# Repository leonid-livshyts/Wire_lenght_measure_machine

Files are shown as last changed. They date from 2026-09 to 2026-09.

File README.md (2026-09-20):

# Intro

It's machine which will count how much wire have gone though it and wind a new rope hank with an acurate length. It consists of roll which is connected to the encoder by gears and counts how much string have gone through it and a motor which pulls the string through the machine. It's controlled by RP2350b. The display and additional encoder will help to set the length of needed hank and to calibrate the mechanism. The mechanism is powered with 12V, 2A power supply. It has a small motor driver to controll speed and smothly controll the stop of the machine. 

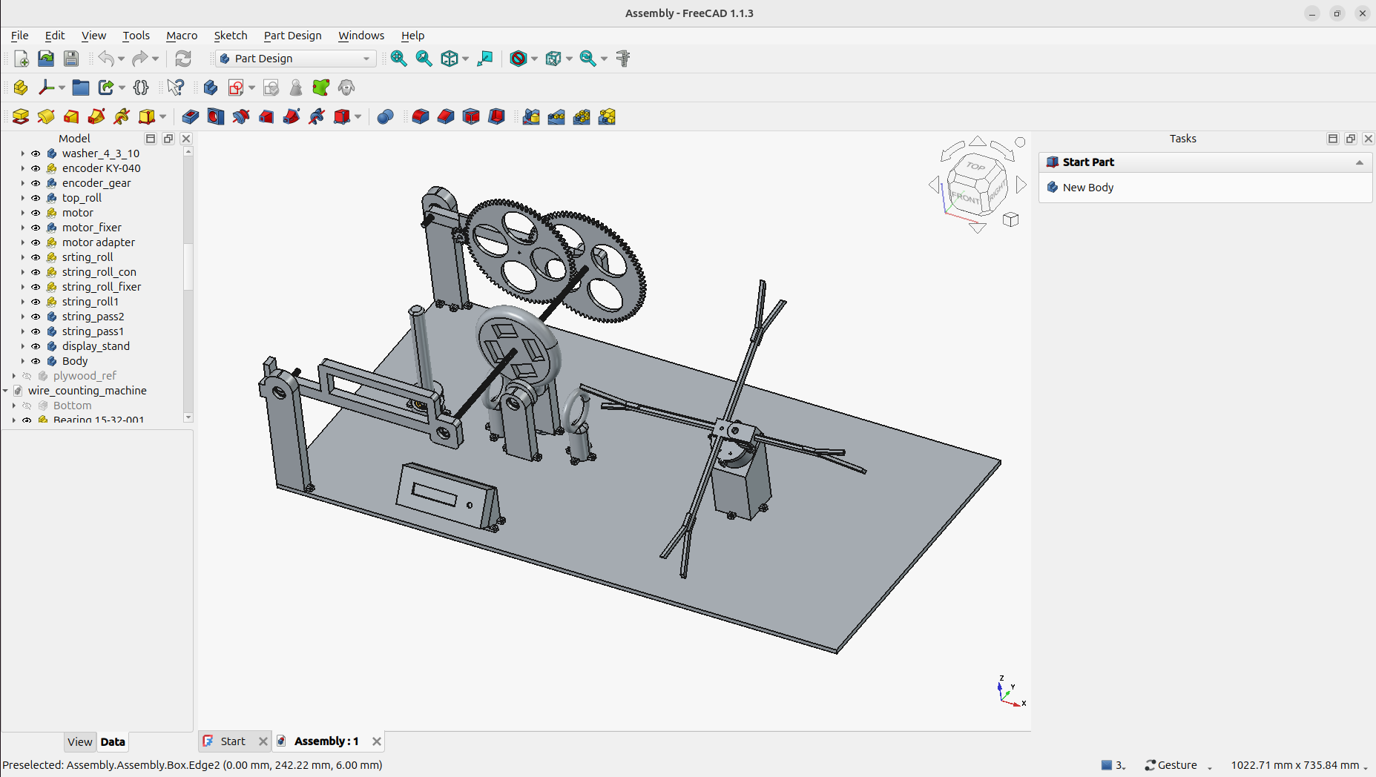
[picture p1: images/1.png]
Design without places for electronics


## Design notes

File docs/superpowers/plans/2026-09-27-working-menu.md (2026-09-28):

# Working Menu Implementation Plan

> **For agentic workers:** REQUIRED SUB-SKILL: Use superpowers:subagent-driven-development (recommended) or superpowers:executing-plans to implement this plan task-by-task. Steps use checkbox (`- [ ]`) syntax for tracking.

**Goal:** Replace the placeholder Working menu (`run 1` / `run 2`) with the real five-page flow: set the target length, set the max speed, thread the wire (counting on, motor off), pull (motor on, long-click pause/resume, stall stop, slow-down to a closed-loop creep speed and stop at target − 1 mm), and show the final length.

**Architecture:** Same split as the calibration menu.
- Hardware-free, host-tested pieces:
  - `ClickDetector` also reports **long clicks**.
  - `Menu` / `MenuManager` pass a user-knob long click to the shown tab.
  - `KnobAccel` gets an optional ×1000 step and a `clampAdd()` helper.
  - `run_logic.{h,cpp}` holds the pure maths of a run: when to slow down and stop, `SpeedMeter`, `CreepController` (holds the creep speed by measuring the wire), `StallDetector`.
- `Motor` gets `setSpeed(speed, ramp_ms)` (an exact power with its own ramp time, 0 = at once) and `isRamping()`, so the creep phase can steer the power and stop instantly.
- SDK-touching pages:
  - `number_edit_tab.{h,cpp}` is a generic "edit a number with the knob" page. It is used by the working menu's pages 1–2 and replaces `CalLengthTab`.
  - `working_menu.{h,cpp}` holds pages 3–5 and `WorkingMenu`.

**Tech Stack:** C++17, Raspberry Pi Pico SDK 2.3.1 (RP2350B, Ninja), host tests with the system `g++` and the existing `CHECK` macro.

## Global Constraints

- The pages, in order (from the user's spec):
  1. **Length:** the user sets the wanted wire length with the user knob. Uses the calibration menu's speed-dependent step.
  2. **Max speed:** in percent, default **100 %**, with the same knob system.
  3. **Thread:** counting is active and the display shows how much wire has gone through, but the **motor does not start**. The user puts the wire into the machine.
  4. **Pull:** the motor starts and the display shows the pulled length.
     - A **long click** pauses the motor, and another long click resumes it. The measuring encoder keeps counting while paused.
     - A **short click** goes to page 5. The page never advances by itself.
     - If the target is not reached yet and the motor runs while the measuring encoder sees **no movement for 10 s**, the motor stops.
  5. **Done:** stop the motor if it is not stopped already, show the final length, and stop counting.
- User decisions (asked 2026-09-27):
  - **Long click** = the user knob is released after being held **more than 2 s** (`ClickDetector::kShortClickMaxMs`). Nothing happens while it is held. A press of 2 s or less is a short click, as today.
  - **Target reached:** brake **early**, so the wire stops as close to the target as possible. The motor is not started at all if the target is already reached.
  - **Landing (user, 2026-09-28):** one fixed braking distance cannot be right, so the machine steers by the measured speed instead. Near the target, the motor slows down to a **creep speed in mm/s**. That speed is a constant, to be determined on the machine. During the creep the power is corrected from the measured wire speed. When the pulled length reaches **target − 1 mm**, the motor stops **at once**.
  - Target length and speed are **kept in RAM** between runs. At power-up they are reset to the defaults (1000 mm, 100 %). **Nothing is written to flash.**
  - The length is shown in **mm**. The knob step is **1 / 10 / 100 / 1000 mm** per detent, depending on turning speed.
- Page 1 range: **1 … 99 999 999 mm** (8 digits), default **1000**. Page 2 range: **1 … 100 %**, step ×1 / ×10 at most (×100 would just jump to a limit).
- Display texts (the font has no `M`/`X`):
  - Page 2 shows `SP` plus the number, right-aligned (`SP   100`).
  - A pulled length that needs more than 8 digits shows `--------`, as in calibration.
  - While paused or stalled, page 4 **blinks** (500 ms on / 500 ms off).
- The pulled length is `ticksToMm(measure.getCount(), settings.mm_per_tick)` (from `calibration.h`). The sign of the count is ignored.
- Stall detection runs **only while the motor is driving**: running, slowing down or creeping. It does not run while paused or stopped. One count step of jitter is not movement: movement is **≥ 4 ticks** (one detent).
- Landing model (every constant marked TUNE is a first guess, to be set on the machine):
  - **Slow-down point.** `Motor` ramps along a smoothstep over `Motor::kDefaultRampMs`, and a smoothstep's average is the mean of the start and end speeds. Ramping from speed `v` down to the creep speed therefore passes `(v + kCreepSpeedMmPerS) / 2 × ramp`. The slow-down starts when `pulled + that distance + kCreepMinMm ≥ target`.
    - `kCreepSpeedMmPerS = 20` (TUNE)
    - `kCreepMinMm = 20` (TUNE): the shortest creep, so the speed has time to settle.
  - **First creep power.** Wire speed is assumed proportional to power, so the first guess is `current power × creep / measured speed`. It is clamped to `[kCreepMinPower, current power]`.
  - **Creep control.** Every `SpeedMeter::kWindowMs` (100 ms), `power += kCreepGainPerMmS × (creep − measured)`, clamped to `[kCreepMinPower, max speed %]`.
    - `kCreepMinPower = 0.05` (TUNE)
    - `kCreepGainPerMmS = 0.002` (TUNE)
    - Power changes use a 100 ms ramp (`kCreepRampMs`).
    - The last creep power is remembered and used when a run resumes close to the target.
  - **Stop.** At `pulled ≥ target − kStopBeforeMm`, where `kStopBeforeMm = 1`, the power is set to 0 at once (`Motor::setSpeed(0, 0)`).
  - **Short target or resume.** If the target is no more than `kCreepMinMm` away when the motor starts or resumes, there is no fast phase: it creeps straight away.
- The hardware-free files (`click_detector.*`, `menu*.*`, `knob_accel.*`, `run_logic.*`) must not include Pico SDK headers.
- No heap: no `new`, `std::function`, `std::vector` or `std::string`.
- Code style: `snake_case_` members, `camelCase()` methods, `kConstant` constants, 4-space indent, `#pragma once`, and the comment density of the existing files.
- Every new firmware `.cpp` goes into `add_executable(Code ...)` in `Code/CMakeLists.txt`. Every new hardware-free `.cpp` also goes into `SOURCES` in `Code/tests/run_tests.sh`. Do not edit the `DO NOT EDIT` block.
- The working tree has unrelated changes (Case/, PCB/). **Commit only the paths listed in each task** (`git commit -- <paths>` after `git add <paths>`). Never use `git add -A` or `git commit -a`.

## File Structure

All paths are relative to the repository root.

| File | Responsibility |
|---|---|
| `Code/click_detector.{h,cpp}` (modify) | `ClickEvent { None, Short, Long }`; `update()` returns it |
| `Code/menu.{h,cpp}` (modify) | `MenuTab::onLongClick()`, `Menu::longClick()` |
| `Code/menu_manager.{h,cpp}` (modify) | `MenuInput::user_long_click`, forwarded to the open menu |
| `Code/knob_accel.{h,cpp}` (modify) | `max_factor` cap, ×1000 level, `clampAdd()` |
| `Code/run_logic.{h,cpp}` (create) | Target/speed limits, landing constants, `slowDownDistanceMm()`, `shouldSlowDown()`, `shouldStop()`, `estimateCreepPower()`, `SpeedMeter`, `CreepController`, `StallDetector` |
| `Code/motor.{h,cpp}` (modify) | `setSpeed(speed, ramp_ms)`, `isRamping()`; per-ramp duration |
| `Code/number_edit_tab.{h,cpp}` (create) | `NumberEditTab`: generic knob-edited number page with an optional 2-char label |
| `Code/calibration_menu.{h,cpp}` (modify) | `CalLengthTab` replaced by `NumberEditTab` |
| `Code/working_menu.{h,cpp}` (create) | `WorkingContext`, `RunThreadTab`, `RunPullTab`, `RunDoneTab`, `WorkingMenu` |
| `Code/Code.cpp` (modify) | Long clicks into `MenuInput`; real Working menu instead of the placeholders |
| `Code/CMakeLists.txt` (modify) | New sources |
| `Code/tests/*` (modify / create) | Tests per unit, registration |
| `Code/CLAUDE.md`, `Instructions/working.md` (modify / create) | Developer and user docs |

Commands used throughout (run from the repo root):
- Host tests: `Code/tests/run_tests.sh` → last line `All tests passed`
- Firmware build: `~/.pico-sdk/ninja/v1.13.2/ninja -C Code/build` → ends without `error:`, and `Code/build/Code.uf2` is updated

---

### Task 1: Long clicks in `ClickDetector`

**Files:**
- Modify: `Code/click_detector.h`, `Code/click_detector.cpp`
- Modify: `Code/tests/test_click_detector.cpp`
- Modify: `Code/Code.cpp` (keep the firmware compiling)

**Interfaces:**
- Consumes: nothing new.
- Produces: `enum class ClickEvent : uint8_t { None, Short, Long };` and `ClickEvent ClickDetector::update(bool pressed, uint32_t now_ms)`. On release, the result is `Short` if the press lasted ≤ `max_short_ms`, otherwise `Long`. It is `None` in every other pass.

- [ ] **Step 1: Rewrite the tests for the new return type**

Replace the whole content of `Code/tests/test_click_detector.cpp` with:

```cpp
#include "check.h"
#include "click_detector.h"

namespace {

void testNoPressNoClick() {
    ClickDetector d;
    CHECK(d.update(false, 0) == ClickEvent::None);
    CHECK(d.update(false, 100) == ClickEvent::None);
}

void testShortPressClicksOnceOnRelease() {
    ClickDetector d;
    CHECK(d.update(true, 1000) == ClickEvent::None);   // pressed: nothing yet
    CHECK(d.update(true, 1100) == ClickEvent::None);   // still held
    CHECK(d.update(false, 1150) == ClickEvent::Short); // released after 150 ms
    CHECK(d.update(false, 1200) == ClickEvent::None);  // reported only once
}

void testPressExactlyAtLimitIsShort() {
    ClickDetector d;
    d.update(true, 0);
    CHECK(d.update(false, ClickDetector::kShortClickMaxMs) == ClickEvent::Short);
}

void testLongPressReportsLongOnRelease() {
    ClickDetector d;
    d.update(true, 0);
    CHECK(d.update(true, 5000) == ClickEvent::None);  // nothing while held, however long
    CHECK(d.update(false, 5001) == ClickEvent::Long);
    CHECK(d.update(false, 5100) == ClickEvent::None); // reported only once
}

void testJustOverLimitIsLong() {
    ClickDetector d;
    d.update(true, 0);
    CHECK(d.update(false, ClickDetector::kShortClickMaxMs + 1) == ClickEvent::Long);
}

void testCustomLimit() {
    ClickDetector d(500);
    d.update(true, 0);
    CHECK(d.update(false, 600) == ClickEvent::Long);   // 600 ms > 500 ms
    d.update(true, 1000);
    CHECK(d.update(false, 1400) == ClickEvent::Short); // 400 ms
}

void testMillisecondCounterWraparound() {
    ClickDetector d;
    d.update(true, 0xFFFFFF00u);                      // 256 ms before the uint32_t wrap
    CHECK(d.update(false, 100) == ClickEvent::Short); // 356 ms later
    d.update(true, 0xFFFFFF00u);
    CHECK(d.update(false, 3000) == ClickEvent::Long); // 3256 ms later
}

}  // namespace

void runClickDetectorTests() {
    testNoPressNoClick();
    testShortPressClicksOnceOnRelease();
    testPressExactlyAtLimitIsShort();
    testLongPressReportsLongOnRelease();
    testJustOverLimitIsLong();
    testCustomLimit();
    testMillisecondCounterWraparound();
}
```

- [ ] **Step 2: Run the tests and check that they fail**

Run: `Code/tests/run_tests.sh`
Expected: compile error, `'ClickEvent' has not been declared`.

- [ ] **Step 3: Implement `ClickEvent`**

Replace the whole content of `Code/click_detector.h` with:

```cpp
#pragma once

#include <stdint.h>

// What one press of a button turned out to be, reported on release.
enum class ClickEvent : uint8_t {
    None,   // no release in this pass
    Short,  // held for at most max_short_ms: flips menu pages
    Long,   // held longer: e.g. pause/resume while pulling wire
};

// Turns a debounced button level into short and long clicks.
//
// Both are reported once, on release, so nothing happens while the button
// is held. Pure logic (no SDK calls), so it is unit-tested on the host; the
// caller passes the time in.
class ClickDetector {
public:
    static constexpr uint32_t kShortClickMaxMs = 2000;

    explicit ClickDetector(uint32_t max_short_ms = kShortClickMaxMs);

    // Call regularly with the current button state and time. Returns Short
    // or Long exactly once per press (on release), None otherwise.
    // now_ms may wrap around.
    ClickEvent update(bool pressed, uint32_t now_ms);

private:
    uint32_t max_short_ms_;
    bool was_pressed_ = false;
    uint32_t press_start_ms_ = 0;
};
```

Replace the whole content of `Code/click_detector.cpp` with:

```cpp
#include "click_detector.h"

ClickDetector::ClickDetector(uint32_t max_short_ms) : max_short_ms_(max_short_ms) {}

ClickEvent ClickDetector::update(bool pressed, uint32_t now_ms) {
    if (pressed && !was_pressed_) press_start_ms_ = now_ms;
    bool released = !pressed && was_pressed_;
    was_pressed_ = pressed;
    if (!released) return ClickEvent::None;

    // Unsigned subtraction keeps the duration right across a counter wrap
    return (uint32_t)(now_ms - press_start_ms_) <= max_short_ms_ ? ClickEvent::Short
                                                                 : ClickEvent::Long;
}
```

In `Code/Code.cpp`, in the main loop, replace:

```cpp
        input.user_click = userClicks.update(userEncoder.isPressed(), now);
        input.measure_click = measureClicks.update(measureEncoder.isPressed(), now);
```

with:

```cpp
        input.user_click = userClicks.update(userEncoder.isPressed(), now) == ClickEvent::Short;
        input.measure_click = measureClicks.update(measureEncoder.isPressed(), now) == ClickEvent::Short;
```

- [ ] **Step 4: Run the tests and the firmware build**

Run: `Code/tests/run_tests.sh` → Expected: `All tests passed`
Run: `~/.pico-sdk/ninja/v1.13.2/ninja -C Code/build` → Expected: builds without errors.

- [ ] **Step 5: Commit**

```bash
git add Code/click_detector.h Code/click_detector.cpp Code/tests/test_click_detector.cpp Code/Code.cpp
git commit -m "feat(firmware): report long clicks from ClickDetector" -- Code/click_detector.h Code/click_detector.cpp Code/tests/test_click_detector.cpp Code/Code.cpp
```

---

### Task 2: Long click through `Menu` and `MenuManager`

**Files:**
- Modify: `Code/menu.h`, `Code/menu.cpp`, `Code/menu_manager.h`, `Code/menu_manager.cpp`
- Modify: `Code/tests/fake_tab.h`, `Code/tests/test_menu.cpp`, `Code/tests/test_menu_manager.cpp`
- Modify: `Code/Code.cpp`

**Interfaces:**
- Consumes: `ClickEvent` (Task 1).
- Produces:
  - `virtual TabAction MenuTab::onLongClick()`, default `TabAction::Stay`.
  - `void Menu::longClick()`, ignored while the menu is closed.
  - `bool MenuInput::user_long_click`. It is forwarded to the open menu. It **never opens a menu** while idle.

- [ ] **Step 1: Extend `FakeTab`**

In `Code/tests/fake_tab.h`, add the members below after `bool skipped = false;  // isSkipped() result`:

```cpp
    int long_clicks = 0;
    TabAction long_click_action = TabAction::Stay;
```

and this override after the `onClick()` override:

```cpp
    TabAction onLongClick() override { long_clicks++; return long_click_action; }
```

- [ ] **Step 2: Write the failing menu tests**

In `Code/tests/test_menu.cpp`, add these inside the anonymous namespace, before its closing `}  // namespace`:

```cpp
void testLongClickGoesToShownTab() {
    FakeTab a, b;
    Menu m;
    m.addTab(a);
    m.addTab(b);
    m.open();
    m.longClick();
    CHECK(a.long_clicks == 1);
    CHECK(a.clicks == 0);
    CHECK(m.currentTab() == 0);  // default: Stay

    a.long_click_action = TabAction::Next;
    m.longClick();
    CHECK(m.currentTab() == 1);
    CHECK(b.long_clicks == 0);
}

void testLongClickWhileClosedIsIgnored() {
    FakeTab a;
    Menu m;
    m.addTab(a);
    m.longClick();
    CHECK(a.long_clicks == 0);
    CHECK(!m.isOpen());
}
```

and add at the end of `runMenuTests()`:

```cpp
    testLongClickGoesToShownTab();
    testLongClickWhileClosedIsIgnored();
```

In `Code/tests/test_menu_manager.cpp`, add this helper after `MenuInput userTurn(...)`:

```cpp
MenuInput userLongClick() { MenuInput in; in.user_long_click = true; return in; }
```

add these tests inside the anonymous namespace, before its closing `}  // namespace`:

```cpp
void testLongClickDoesNotOpenMenu() {
    Fixture f;
    f.manager.process(userLongClick(), 0);
    CHECK(f.manager.activeMenu() == nullptr);
    CHECK(f.work1.enters == 0);
    CHECK(f.cal1.enters == 0);
}

void testLongClickReachesOpenTab() {
    Fixture f;
    f.manager.process(userClick(), 0);
    f.manager.process(userLongClick(), 5);
    CHECK(f.work1.long_clicks == 1);
    CHECK(f.work1.clicks == 0);
    CHECK(f.manager.activeMenu() == &f.working);
}
```

and add at the end of `runMenuManagerTests()`:

```cpp
    testLongClickDoesNotOpenMenu();
    testLongClickReachesOpenTab();
```

- [ ] **Step 3: Run the tests and check that they fail**

Run: `Code/tests/run_tests.sh`
Expected: compile errors, e.g. `'class Menu' has no member named 'longClick'`, and `'onLongClick' marked 'override', but does not override`.

- [ ] **Step 4: Implement**

In `Code/menu.h`, in `MenuTab`, after the `onClick()` declaration add:

```cpp
    // Long click on the user encoder (held > 2 s, reported on release).
    // Default: ignored.
    virtual TabAction onLongClick() { return TabAction::Stay; }
```

In `Code/menu.h`, in `Menu`, change the input declarations to:

```cpp
    // Input for the shown tab; ignored while closed.
    void turn(int32_t detents);
    void click();
    void longClick();
    void update(uint32_t now_ms);
```

In `Code/menu.cpp`, after `Menu::click()` add:

```cpp
void Menu::longClick() {
    if (isOpen()) apply(tabs_[current_]->onLongClick());
}
```

In `Code/menu_manager.h`, change `MenuInput` to:

```cpp
struct MenuInput {
    int32_t user_turn = 0;         // user knob detents since the last pass
    bool user_click = false;       // short click on the user knob
    bool user_long_click = false;  // long click on the user knob; never opens a menu
    bool measure_click = false;    // short click on the measuring-roll encoder
};
```

In `Code/menu_manager.cpp`, in `process()`, change the open-menu branch to:

```cpp
        active_->turn(input.user_turn);
        if (input.user_click) active_->click();
        if (input.user_long_click) active_->longClick();
```

In `Code/Code.cpp`, replace the line

```cpp
        input.user_click = userClicks.update(userEncoder.isPressed(), now) == ClickEvent::Short;
```

with:

```cpp
        ClickEvent user_click = userClicks.update(userEncoder.isPressed(), now);
        input.user_click = user_click == ClickEvent::Short;
        input.user_long_click = user_click == ClickEvent::Long;
```

- [ ] **Step 5: Run the tests and the firmware build**

Run: `Code/tests/run_tests.sh` → Expected: `All tests passed`
Run: `~/.pico-sdk/ninja/v1.13.2/ninja -C Code/build` → Expected: builds without errors.

- [ ] **Step 6: Commit**

```bash
git add Code/menu.h Code/menu.cpp Code/menu_manager.h Code/menu_manager.cpp Code/tests/fake_tab.h Code/tests/test_menu.cpp Code/tests/test_menu_manager.cpp Code/Code.cpp
git commit -m "feat(firmware): pass user-knob long clicks to the shown tab" -- Code/menu.h Code/menu.cpp Code/menu_manager.h Code/menu_manager.cpp Code/tests/fake_tab.h Code/tests/test_menu.cpp Code/tests/test_menu_manager.cpp Code/Code.cpp
```

---

### Task 3: `KnobAccel` ×1000 level and `clampAdd()`

**Files:**
- Modify: `Code/knob_accel.h`, `Code/knob_accel.cpp`, `Code/tests/test_knob_accel.cpp`

**Interfaces:**
- Consumes: nothing new.
- Produces:
  - `explicit KnobAccel(int32_t max_factor = 100)`. The step is ×1000 for gaps ≤ `kFastestGapMs` (20 ms), then capped at `max_factor`. The default of 100 keeps the calibration page exactly as it is today.
  - `int32_t clampAdd(int32_t value, int32_t delta, int32_t min_value, int32_t max_value)`: overflow-safe add, then clamp.

- [ ] **Step 1: Write the failing tests**

In `Code/tests/test_knob_accel.cpp`, add inside the anonymous namespace, before `}  // namespace`:

```cpp
void testFastestTurnsNeedCap1000() {
    KnobAccel wide(1000);
    wide.scale(1, 1000);
    CHECK(wide.scale(1, 1000 + KnobAccel::kFastestGapMs) == 1000);
    CHECK(wide.scale(-1, 1020 + KnobAccel::kFastGapMs) == -100);  // 40 ms: x100

    KnobAccel normal;  // default cap 100: calibration unchanged
    normal.scale(1, 1000);
    CHECK(normal.scale(1, 1000 + KnobAccel::kFastestGapMs) == 100);
}

void testSmallCap() {
    KnobAccel narrow(10);
    narrow.scale(1, 1000);
    CHECK(narrow.scale(1, 1005) == 10);  // fastest turn still only x10
    CHECK(narrow.scale(1, 5000) == 1);
}

void testClampAdd() {
    CHECK(clampAdd(50, 10, 1, 100) == 60);
    CHECK(clampAdd(95, 10, 1, 100) == 100);
    CHECK(clampAdd(5, -10, 1, 100) == 1);
    CHECK(clampAdd(INT32_MAX - 1, INT32_MAX, 1, INT32_MAX) == INT32_MAX);  // no overflow
    CHECK(clampAdd(1, INT32_MIN, 1, 100) == 1);
}
```

Add `#include <cstdint>` at the top of the file, and add at the end of `runKnobAccelTests()`:

```cpp
    testFastestTurnsNeedCap1000();
    testSmallCap();
    testClampAdd();
```

- [ ] **Step 2: Run the tests and check that they fail**

Run: `Code/tests/run_tests.sh`
Expected: compile errors: `'kFastestGapMs' is not a member of 'KnobAccel'`, and `'clampAdd' was not declared`.

- [ ] **Step 3: Implement**

Replace the whole content of `Code/knob_accel.h` with:

```cpp
#pragma once

#include <stdint.h>

// Speed-dependent step for editing a number with the user knob: slow turns
// change it by 1 per detent, faster turns by 10, 100 or 1000, so both fine
// adjustment and big jumps are quick. Pure logic; the caller passes the time.
class KnobAccel {
public:
    static constexpr uint32_t kFastestGapMs = 20;  // turns this close: x1000
    static constexpr uint32_t kFastGapMs = 40;     // turns this close: x100
    static constexpr uint32_t kMediumGapMs = 100;  // turns this close: x10

    // max_factor caps the step: 100 by default, 1000 for long lengths,
    // 10 for small ranges where x100 would only jump to a limit.
    explicit KnobAccel(int32_t max_factor = 100) : max_factor_(max_factor) {}

    // Returns detents scaled by the factor for the gap since the previous
    // turn. detents == 0 returns 0 and is not counted as a turn. now_ms may wrap around.
    int32_t scale(int32_t detents, uint32_t now_ms);

    // Forgets the previous turn, so the next one is x1.
    void reset();

private:
    int32_t max_factor_;
    bool has_last_ = false;
    uint32_t last_ms_ = 0;
};

// value + delta, clamped to [min_value, max_value]. Safe for any int32 inputs.
int32_t clampAdd(int32_t value, int32_t delta, int32_t min_value, int32_t max_value);
```

Replace the whole content of `Code/knob_accel.cpp` with:

```cpp
#include "knob_accel.h"

int32_t KnobAccel::scale(int32_t detents, uint32_t now_ms) {
    if (detents == 0) return 0;
    int32_t factor = 1;
    if (has_last_) {
        uint32_t gap = now_ms - last_ms_;  // unsigned: correct across the wrap
        if (gap <= kFastestGapMs) {
            factor = 1000;
        } else if (gap <= kFastGapMs) {
            factor = 100;
        } else if (gap <= kMediumGapMs) {
            factor = 10;
        }
    }
    if (factor > max_factor_) factor = max_factor_;
    has_last_ = true;
    last_ms_ = now_ms;
    return detents * factor;
}

void KnobAccel::reset() {
    has_last_ = false;
}

int32_t clampAdd(int32_t value, int32_t delta, int32_t min_value, int32_t max_value) {
    int64_t sum = (int64_t)value + delta;  // int64: no overflow
    if (sum < min_value) return min_value;
    if (sum > max_value) return max_value;
    return (int32_t)sum;
}
```

- [ ] **Step 4: Run the tests**

Run: `Code/tests/run_tests.sh` → Expected: `All tests passed`. This includes the old KnobAccel tests, which are unchanged.

- [ ] **Step 5: Commit**

```bash
git add Code/knob_accel.h Code/knob_accel.cpp Code/tests/test_knob_accel.cpp
git commit -m "feat(firmware): optional x1000 knob step and clampAdd helper" -- Code/knob_accel.h Code/knob_accel.cpp Code/tests/test_knob_accel.cpp
```

---

### Task 4: Run maths (`run_logic.{h,cpp}`)

**Files:**
- Create: `Code/run_logic.h`, `Code/run_logic.cpp`, `Code/tests/test_run_logic.cpp`
- Modify: `Code/tests/run_tests.sh`, `Code/tests/test_main.cpp`

**Interfaces:**
- Consumes: nothing.
- Produces (all in `run_logic.h`):
  - `kMinTargetMm = 1`, `kMaxTargetMm = 99999999`, `kDefaultTargetMm = 1000`
  - `kMinSpeedPercent = 1`, `kMaxSpeedPercent = 100`, `kDefaultSpeedPercent = 100`
  - `kCreepSpeedMmPerS = 20.0`, `kCreepMinMm = 20`, `kStopBeforeMm = 1`, `kCreepMinPower = 0.05f`, `kCreepGainPerMmS = 0.002f`
  - `double slowDownDistanceMm(double speed_mm_per_s, uint32_t ramp_ms)`
  - `bool shouldSlowDown(int64_t pulled_mm, int32_t target_mm, double speed_mm_per_s, uint32_t ramp_ms)`
  - `bool shouldStop(int64_t pulled_mm, int32_t target_mm)`
  - `float estimateCreepPower(float power, double speed_mm_per_s)`
  - `class SpeedMeter { void reset(int64_t mm, uint32_t now_ms); double update(int64_t mm, uint32_t now_ms); }`, with `kWindowMs = 100`
  - `class CreepController { void start(float power, float max_power, uint32_t now_ms); float update(double speed_mm_per_s, uint32_t now_ms); float power() const; }`
  - `class StallDetector { void reset(int32_t count, uint32_t now_ms); bool update(int32_t count, uint32_t now_ms); }`, with `kTimeoutMs = 10000` and `kMinMoveTicks = 4`

The tests compute their expected values from the TUNE constants, so they keep passing after the constants are tuned.

- [ ] **Step 1: Write the failing tests**

Create `Code/tests/test_run_logic.cpp`:

```cpp
#include <cmath>

#include "check.h"
#include "run_logic.h"

namespace {

bool near(double a, double b) { return std::fabs(a - b) < 1e-6; }

void testSlowDownDistance() {
    // Smoothstep ramp from 120 mm/s to the creep speed over 2.5 s
    CHECK(near(slowDownDistanceMm(120.0, 2500), (120.0 + kCreepSpeedMmPerS) / 2.0 * 2.5));
    CHECK(near(slowDownDistanceMm(kCreepSpeedMmPerS, 2500), 0.0));  // already at creep speed
    CHECK(near(slowDownDistanceMm(0.0, 2500), 0.0));
}

void testShouldSlowDown() {
    double lead = slowDownDistanceMm(120.0, 2500) + kCreepMinMm;
    int64_t at = 1000 - (int64_t)std::floor(lead);  // first whole mm where the lead reaches 1000
    CHECK(shouldSlowDown(at, 1000, 120.0, 2500));
    CHECK(!shouldSlowDown(at - 1, 1000, 120.0, 2500));
    // Standing still: only the creep distance is needed
    CHECK(shouldSlowDown(1000 - kCreepMinMm, 1000, 0.0, 2500));
    CHECK(!shouldSlowDown(1000 - kCreepMinMm - 1, 1000, 0.0, 2500));
}

void testShouldStop() {
    CHECK(shouldStop(1000 - kStopBeforeMm, 1000));
    CHECK(!shouldStop(1000 - kStopBeforeMm - 1, 1000));
    CHECK(shouldStop(1005, 1000));  // overshot
}

void testEstimateCreepPower() {
    CHECK(near(estimateCreepPower(1.0f, kCreepSpeedMmPerS * 5.0), 0.2));  // speed ~ power
    CHECK(near(estimateCreepPower(0.5f, kCreepSpeedMmPerS / 2.0), 0.5));  // never above the current power
    CHECK(near(estimateCreepPower(0.3f, 0.0), 0.3));                      // no speed yet: keep the power
    CHECK(near(estimateCreepPower(1.0f, kCreepSpeedMmPerS * 1000.0), kCreepMinPower));
    CHECK(near(estimateCreepPower(0.02f, 0.0), kCreepMinPower));
}

void testCreepControllerAdjustsEveryWindow() {
    CreepController c;
    c.start(0.2f, 1.0f, 0);
    CHECK(near(c.update(kCreepSpeedMmPerS - 10.0, SpeedMeter::kWindowMs - 1), 0.2));  // not yet
    double faster = 0.2 + 10.0 * kCreepGainPerMmS;                                     // too slow: more power
    CHECK(near(c.update(kCreepSpeedMmPerS - 10.0, SpeedMeter::kWindowMs), faster));
    CHECK(near(c.update(kCreepSpeedMmPerS + 10.0, 2 * SpeedMeter::kWindowMs), 0.2)); // too fast: less
    CHECK(near(c.power(), 0.2));
}

void testCreepControllerClamps() {
    CreepController c;
    c.start(0.0f, 1.0f, 0);
    CHECK(near(c.power(), kCreepMinPower));
    CHECK(near(c.update(kCreepSpeedMmPerS + 1000.0, SpeedMeter::kWindowMs), kCreepMinPower));
    c.start(0.9f, 0.5f, 0);  // user max speed 50 %
    CHECK(near(c.power(), 0.5));
    CHECK(near(c.update(0.0, SpeedMeter::kWindowMs), 0.5));
}

void testSpeedMeterNeedsFullWindow() {
    SpeedMeter m;
    m.reset(0, 1000);
    CHECK(near(m.update(5, 1050), 0.0));     // window not full yet
    CHECK(near(m.update(10, 1100), 100.0));  // 10 mm in 100 ms
    CHECK(near(m.update(12, 1150), 100.0));  // keeps the last value mid-window
    CHECK(near(m.update(30, 1200), 200.0));  // 20 mm in the next 100 ms
}

void testSpeedMeterResetClearsSpeed() {
    SpeedMeter m;
    m.reset(0, 0);
    m.update(50, 100);
    m.reset(50, 200);
    CHECK(near(m.update(50, 250), 0.0));
}

void testSpeedMeterWraparound() {
    SpeedMeter m;
    m.reset(0, 0xFFFFFFC0u);                        // 64 ms before the wrap
    CHECK(near(m.update(10, 0x00000024u), 100.0));  // 100 ms later
}

void testStallAfterTimeout() {
    StallDetector s;
    s.reset(0, 0);
    CHECK(!s.update(0, StallDetector::kTimeoutMs - 1));
    CHECK(s.update(0, StallDetector::kTimeoutMs));
}

void testJitterIsNotMovement() {
    StallDetector s;
    s.reset(100, 0);
    CHECK(!s.update(103, 5000));                     // 3 ticks: jitter
    CHECK(s.update(97, StallDetector::kTimeoutMs));  // still no real movement
}

void testMovementRestartsTimeout() {
    StallDetector s;
    s.reset(0, 0);
    CHECK(!s.update(4, 5000));  // one detent: moving
    CHECK(!s.update(4, 14999));
    CHECK(s.update(4, 15000));
    StallDetector back;
    back.reset(0, 0);
    CHECK(!back.update(-4, 5000));  // either direction counts
    CHECK(!back.update(-4, 14999));
}

void testStallWraparound() {
    StallDetector s;
    s.reset(0, 0xFFFFF000u);
    CHECK(!s.update(0, 0x00001000u));  // 8192 ms across the wrap
}

}  // namespace

void runRunLogicTests() {
    testSlowDownDistance();
    testShouldSlowDown();
    testShouldStop();
    testEstimateCreepPower();
    testCreepControllerAdjustsEveryWindow();
    testCreepControllerClamps();
    testSpeedMeterNeedsFullWindow();
    testSpeedMeterResetClearsSpeed();
    testSpeedMeterWraparound();
    testStallAfterTimeout();
    testJitterIsNotMovement();
    testMovementRestartsTimeout();
    testStallWraparound();
}
```

In `Code/tests/test_main.cpp`, add `void runRunLogicTests();` after `void runCalibrationTests();`, and `runRunLogicTests();` after `runCalibrationTests();`.

In `Code/tests/run_tests.sh`, change the `SOURCES` line to:

```sh
SOURCES="../click_detector.cpp ../menu.cpp ../menu_manager.cpp ../knob_accel.cpp ../settings.cpp ../calibration.cpp ../run_logic.cpp"
```

- [ ] **Step 2: Run the tests and check that they fail**

Run: `Code/tests/run_tests.sh`
Expected: `fatal error: run_logic.h: No such file or directory`.

- [ ] **Step 3: Implement**

Create `Code/run_logic.h`:

```cpp
#pragma once

#include <stdint.h>

// Pure maths of the working menu (host-tested).

constexpr int32_t kMinTargetMm = 1;
constexpr int32_t kMaxTargetMm = 99999999;  // 8 display digits
constexpr int32_t kDefaultTargetMm = 1000;

constexpr int32_t kMinSpeedPercent = 1;
constexpr int32_t kMaxSpeedPercent = 100;
constexpr int32_t kDefaultSpeedPercent = 100;

// --- Landing on the target ---
// No single braking distance fits every speed and wire, so near the target
// the motor slows down to a creep speed, the power is corrected from the
// measured wire speed, and the motor stops at once kStopBeforeMm before the
// target; the wire coasts the rest. TUNE = first guess, set on the machine.
constexpr double kCreepSpeedMmPerS = 20.0;  // TUNE
constexpr int32_t kCreepMinMm = 20;         // shortest creep, so the speed settles; TUNE
constexpr int32_t kStopBeforeMm = 1;
constexpr float kCreepMinPower = 0.05f;     // lowest motor power while creeping; TUNE
constexpr float kCreepGainPerMmS = 0.002f;  // power change per mm/s of error, per adjustment; TUNE

// Wire that passes while the motor ramps from speed_mm_per_s down to the
// creep speed over ramp_ms. The ramp is a smoothstep, whose average speed is
// the mean of both ends. 0 if already at or below the creep speed.
double slowDownDistanceMm(double speed_mm_per_s, uint32_t ramp_ms);

// True once the motor must start slowing down to still creep kCreepMinMm
// before the target.
bool shouldSlowDown(int64_t pulled_mm, int32_t target_mm, double speed_mm_per_s, uint32_t ramp_ms);

// True once pulled_mm >= target_mm - kStopBeforeMm: stop the motor now.
bool shouldStop(int64_t pulled_mm, int32_t target_mm);

// First guess for the creep power, taking wire speed as proportional to
// power: power * creep / speed, at most `power`, at least kCreepMinPower.
// `power` itself (at least kCreepMinPower) while no speed is measured.
float estimateCreepPower(float power, double speed_mm_per_s);

// Wire speed from the pulled length, measured over windows of kWindowMs.
class SpeedMeter {
public:
    static constexpr uint32_t kWindowMs = 100;

    // Starts measuring from `mm`; the speed is 0 until a full window has passed.
    void reset(int64_t mm, uint32_t now_ms);

    // Call every pass. Returns the speed of the last full window in mm/s.
    // now_ms may wrap around.
    double update(int64_t mm, uint32_t now_ms);

private:
    int64_t window_mm_ = 0;
    uint32_t window_start_ms_ = 0;
    double speed_mm_per_s_ = 0.0;
};

// Holds the creep speed: every SpeedMeter::kWindowMs it moves the motor
// power by kCreepGainPerMmS per mm/s of error (a simple integral controller).
class CreepController {
public:
    // Starts from `power`, clamped to [kCreepMinPower, max_power]
    // (max_power = the user's max speed). The first adjustment comes one
    // window later.
    void start(float power, float max_power, uint32_t now_ms);

    // Call every pass with the measured wire speed. Returns the power to
    // drive. now_ms may wrap around.
    float update(double speed_mm_per_s, uint32_t now_ms);

    // Current power. Kept between runs as the best guess for the next creep.
    float power() const { return power_; }

private:
    float power_ = 0.2f;  // TUNE: guess before any creep has run
    float max_power_ = 1.0f;
    uint32_t last_adjust_ms_ = 0;
};

// Detects "motor driving but the wire does not move" from the raw count.
class StallDetector {
public:
    static constexpr uint32_t kTimeoutMs = 10000;
    static constexpr int32_t kMinMoveTicks = 4;  // one detent; less is encoder jitter

    void reset(int32_t count, uint32_t now_ms);

    // True once the count has not moved by kMinMoveTicks for kTimeoutMs.
    // now_ms may wrap around.
    bool update(int32_t count, uint32_t now_ms);

private:
    int32_t last_count_ = 0;
    uint32_t last_move_ms_ = 0;
};
```

Create `Code/run_logic.cpp`:

```cpp
#include "run_logic.h"

namespace {

// Clamped to [kCreepMinPower, max_power]; the minimum wins if they cross.
float clampPower(float power, float max_power) {
    if (power > max_power) power = max_power;
    if (power < kCreepMinPower) power = kCreepMinPower;
    return power;
}

}  // namespace

double slowDownDistanceMm(double speed_mm_per_s, uint32_t ramp_ms) {
    if (speed_mm_per_s <= kCreepSpeedMmPerS) return 0.0;
    return (speed_mm_per_s + kCreepSpeedMmPerS) / 2.0 * (ramp_ms / 1000.0);
}

bool shouldSlowDown(int64_t pulled_mm, int32_t target_mm, double speed_mm_per_s, uint32_t ramp_ms) {
    double lead = slowDownDistanceMm(speed_mm_per_s, ramp_ms) + kCreepMinMm;
    return (double)pulled_mm + lead >= (double)target_mm;
}

bool shouldStop(int64_t pulled_mm, int32_t target_mm) {
    return pulled_mm >= (int64_t)target_mm - kStopBeforeMm;
}

float estimateCreepPower(float power, double speed_mm_per_s) {
    float guess = speed_mm_per_s > 0.0 ? (float)(power * kCreepSpeedMmPerS / speed_mm_per_s) : power;
    return clampPower(guess, power);
}

void SpeedMeter::reset(int64_t mm, uint32_t now_ms) {
    window_mm_ = mm;
    window_start_ms_ = now_ms;
    speed_mm_per_s_ = 0.0;
}

double SpeedMeter::update(int64_t mm, uint32_t now_ms) {
    uint32_t elapsed = now_ms - window_start_ms_;  // unsigned: correct across the wrap
    if (elapsed >= kWindowMs) {
        speed_mm_per_s_ = (double)(mm - window_mm_) * 1000.0 / (double)elapsed;
        window_mm_ = mm;
        window_start_ms_ = now_ms;
    }
    return speed_mm_per_s_;
}

void CreepController::start(float power, float max_power, uint32_t now_ms) {
    max_power_ = max_power;
    power_ = clampPower(power, max_power);
    last_adjust_ms_ = now_ms;
}

float CreepController::update(double speed_mm_per_s, uint32_t now_ms) {
    if ((uint32_t)(now_ms - last_adjust_ms_) >= SpeedMeter::kWindowMs) {
        float error = (float)(kCreepSpeedMmPerS - speed_mm_per_s);  // > 0: too slow
        power_ = clampPower(power_ + kCreepGainPerMmS * error, max_power_);
        last_adjust_ms_ = now_ms;
    }
    return power_;
}

void StallDetector::reset(int32_t count, uint32_t now_ms) {
    last_count_ = count;
    last_move_ms_ = now_ms;
}

bool StallDetector::update(int32_t count, uint32_t now_ms) {
    int64_t moved = (int64_t)count - last_count_;  // int64: no overflow
    if (moved >= kMinMoveTicks || moved <= -kMinMoveTicks) {
        last_count_ = count;
        last_move_ms_ = now_ms;
        return false;
    }
    return (uint32_t)(now_ms - last_move_ms_) >= kTimeoutMs;
}
```

- [ ] **Step 4: Run the tests**

Run: `Code/tests/run_tests.sh` → Expected: `All tests passed`.

- [ ] **Step 5: Commit**

```bash
git add Code/run_logic.h Code/run_logic.cpp Code/tests/test_run_logic.cpp Code/tests/test_main.cpp Code/tests/run_tests.sh
git commit -m "feat(firmware): landing maths: slow-down point, creep speed control, stall detection" -- Code/run_logic.h Code/run_logic.cpp Code/tests/test_run_logic.cpp Code/tests/test_main.cpp Code/tests/run_tests.sh
```

---

### Task 5: `Motor::setSpeed()` and `isRamping()`

**Files:**
- Modify: `Code/motor.h`, `Code/motor.cpp`

**Interfaces:**
- Consumes: nothing new.
- Produces:
  - `void Motor::setSpeed(float speed, uint32_t ramp_ms)`: drives at exactly `speed` (0.0 … 1.0, **not** limited by the max speed), ramping over `ramp_ms` (0 = at once). `speed > 0` counts as running; `0` stops.
  - `bool Motor::isRamping() const`
  - `start()` / `stop()` / `setMaxSpeed()` keep their behaviour and still use the constructor's `ramp_ms`.

`Motor` uses the SDK, so it has no host test. It is verified by the build and by a hardware check that calibration start/stop is unchanged.

- [ ] **Step 1: Header**

In `Code/motor.h`, after the `isRunning()` declaration add:

```cpp
    // Drives at exactly `speed` (0.0 .. 1.0, not limited by the max speed),
    // reaching it over ramp_ms (0 = at once). 0.0 stops the motor. Used to
    // hold a measured wire speed, e.g. creeping onto the target length.
    void setSpeed(float speed, uint32_t ramp_ms);

    // True while a ramp started by any command is still in progress.
    bool isRamping() const;
```

In the private part, change `void rampTo(float target);` to:

```cpp
    void rampTo(float target, uint64_t ramp_us);
```

change `uint32_t ramp_us_;` to:

```cpp
    uint32_t ramp_us_;  // ramp time of start() / stop() / setMaxSpeed()
```

and in the ramp state block, after `uint64_t ramp_start_us_ = 0;`, add:

```cpp
    uint64_t ramp_len_us_ = 0;  // duration of the current ramp
```

- [ ] **Step 2: Implementation**

In `Code/motor.cpp`, replace `start()`, `stop()` and `setMaxSpeed()` with:

```cpp
void Motor::start() {
    running_ = true;
    rampTo(max_percent_ / 100.0f, ramp_us_);
}

void Motor::stop() {
    running_ = false;
    rampTo(0.0f, ramp_us_);
}

void Motor::setMaxSpeed(uint8_t percent) {
    max_percent_ = percent > 100 ? 100 : percent;
    if (running_) rampTo(max_percent_ / 100.0f, ramp_us_);
}
```

After `isRunning()` add:

```cpp
void Motor::setSpeed(float speed, uint32_t ramp_ms) {
    if (speed < 0.0f) speed = 0.0f;
    if (speed > 1.0f) speed = 1.0f;
    running_ = speed > 0.0f;
    rampTo(speed, (uint64_t)ramp_ms * 1000);
}

bool Motor::isRamping() const {
    return ramping_;
}
```

Replace `rampTo()` with:

```cpp
// Starts a new ramp from wherever the motor is now, so calling stop() in the
// middle of a start (or vice versa) does not cause a speed jump.
void Motor::rampTo(float target, uint64_t ramp_us) {
    uint32_t irq_state = save_and_disable_interrupts();
    ramp_from_ = speed_;
    ramp_to_ = target;
    ramp_start_us_ = time_us_64();
    ramp_len_us_ = ramp_us;
    ramping_ = true;
    restore_interrupts(irq_state);
}
```

In `update()`, replace the two uses of `ramp_us_` with `ramp_len_us_`:

```cpp
    if (ramp_len_us_ == 0 || elapsed >= ramp_len_us_) {
        speed = ramp_to_;
        ramping_ = false;
    } else {
        float t = (float)elapsed / (float)ramp_len_us_;
        speed = ramp_from_ + (ramp_to_ - ramp_from_) * sCurve(t);
    }
```

- [ ] **Step 3: Build and run the tests**

Run: `~/.pico-sdk/ninja/v1.13.2/ninja -C Code/build` → Expected: builds without errors.
Run: `Code/tests/run_tests.sh` → Expected: `All tests passed`.
Run: `grep -n "ramp_us_" Code/motor.cpp` → Expected: only in the constructor, `start()`, `stop()` and `setMaxSpeed()`.

- [ ] **Step 4: Commit**

```bash
git add Code/motor.h Code/motor.cpp
git commit -m "feat(firmware): Motor::setSpeed with its own ramp time, isRamping" -- Code/motor.h Code/motor.cpp
```

---

### Task 6: Generic `NumberEditTab`, replacing `CalLengthTab`

**Files:**
- Create: `Code/number_edit_tab.h`, `Code/number_edit_tab.cpp`
- Modify: `Code/calibration_menu.h`, `Code/calibration_menu.cpp`, `Code/CMakeLists.txt`

**Interfaces:**
- Consumes: `KnobAccel(int32_t max_factor)` and `clampAdd()` (Task 3).
- Produces: `NumberEditTab(Max7219 &display, int32_t &value, int32_t min_value, int32_t max_value, int32_t max_factor, const char *label = nullptr)`.
  - With no label it shows `printNumber(value)`, which is exactly what `CalLengthTab` showed.
  - With a label (≤ 2 chars) it shows the label left and the value right, in a 6-digit field.

This task has no host test, because the tab draws on the SDK `Max7219`. The edit logic it uses (`KnobAccel`, `clampAdd`) is already tested. Verification is the firmware build plus a hardware check that calibration page 1 behaves as before.

- [ ] **Step 1: Create the tab**

Create `Code/number_edit_tab.h`:

```cpp
#pragma once

#include <stdint.h>

#include "knob_accel.h"
#include "menu.h"

class Max7219;

// A page that edits one number with the user knob. The step grows with
// turning speed (KnobAccel, capped at max_factor). The value lives outside
// the tab, so it is kept between menu runs.
class NumberEditTab final : public MenuTab {
public:
    // label: up to 2 characters shown on the left (e.g. "SP"), with the value
    // right-aligned in the remaining 6 digits; nullptr shows the bare number.
    NumberEditTab(Max7219 &display, int32_t &value, int32_t min_value, int32_t max_value,
                  int32_t max_factor, const char *label = nullptr);

    void onEnter() override;
    void onTurn(int32_t detents) override;
    TabAction update(uint32_t now_ms) override;

private:
    void draw();

    Max7219 &display_;
    int32_t &value_;
    int32_t min_value_;
    int32_t max_value_;
    const char *label_;
    KnobAccel accel_;
    uint32_t now_ms_ = 0;  // time of the latest pass, for KnobAccel
};
```

Create `Code/number_edit_tab.cpp`:

```cpp
#include "number_edit_tab.h"

#include <stdio.h>

#include "max7219.h"

NumberEditTab::NumberEditTab(Max7219 &display, int32_t &value, int32_t min_value,
                             int32_t max_value, int32_t max_factor, const char *label)
    : display_(display), value_(value), min_value_(min_value), max_value_(max_value),
      label_(label), accel_(max_factor) {}

void NumberEditTab::onEnter() {
    accel_.reset();
    draw();
}

void NumberEditTab::onTurn(int32_t detents) {
    // now_ms_ is from the previous pass (<= one loop period old): turns are
    // delivered before update() within a pass
    value_ = clampAdd(value_, accel_.scale(detents, now_ms_), min_value_, max_value_);
    draw();
}

TabAction NumberEditTab::update(uint32_t now_ms) {
    now_ms_ = now_ms;
    return TabAction::Stay;
}

void NumberEditTab::draw() {
    if (label_ == nullptr) {
        display_.printNumber(value_);
        return;
    }
    char text[16];
    snprintf(text, sizeof(text), "%-2s%6ld", label_, (long)value_);
    display_.printText(text);
}
```

- [ ] **Step 2: Use it for calibration page 1**

In `Code/calibration_menu.h`:
- Replace `#include "knob_accel.h"` with `#include "number_edit_tab.h"`.
- Delete the whole `CalLengthTab` class, including its comment `// Page 1: length of the test wire in mm, speed-dependent knob step.`
- In `CalibrationMenu`, change the member `CalLengthTab length_;` to:

```cpp
    NumberEditTab length_;  // page 1: length of the test wire in mm
```

In `Code/calibration_menu.cpp`, delete the whole `// --- Page 1: length ---` section (`CalLengthTab::onEnter`, `onTurn`, `update`, `draw`), and change the constructor's initializer list to:

```cpp
CalibrationMenu::CalibrationMenu(CalibrationContext &ctx)
    : ctx_(ctx),
      length_(ctx.display, ctx.length_mm, kMinCalLengthMm, kMaxCalLengthMm, 100),
      mode_(ctx), attach_(ctx), move_(ctx), result_(ctx) {
```

(The `addTab(...)` calls are unchanged. `adjustLength()` stays in `calibration.h`; it is still covered by its tests.)

In `Code/CMakeLists.txt`, add `number_edit_tab.cpp` to the end of the `add_executable(Code ...)` source list:

```cmake
add_executable(Code Code.cpp max7219.cpp rotary_encoder.cpp motor.cpp
        click_detector.cpp menu.cpp menu_manager.cpp knob_accel.cpp settings.cpp calibration.cpp settings_store.cpp calibration_menu.cpp
        number_edit_tab.cpp)
```

- [ ] **Step 3: Build and run the tests**

Run: `~/.pico-sdk/ninja/v1.13.2/ninja -C Code/build` → Expected: builds without errors or warnings about `CalLengthTab`.
Run: `Code/tests/run_tests.sh` → Expected: `All tests passed`.
Run: `grep -rn CalLengthTab Code --include=*.h --include=*.cpp` → Expected: no output.

- [ ] **Step 4: Commit**

```bash
git add Code/number_edit_tab.h Code/number_edit_tab.cpp Code/calibration_menu.h Code/calibration_menu.cpp Code/CMakeLists.txt
git commit -m "refactor(firmware): generic NumberEditTab replaces CalLengthTab" -- Code/number_edit_tab.h Code/number_edit_tab.cpp Code/calibration_menu.h Code/calibration_menu.cpp Code/CMakeLists.txt
```

---

### Task 7: The Working menu pages and wiring

**Files:**
- Create: `Code/working_menu.h`, `Code/working_menu.cpp`
- Modify: `Code/Code.cpp`, `Code/CMakeLists.txt`

**Interfaces:**
- Consumes:
  - `NumberEditTab` (Task 6); `run_logic.h` (Task 4); `Motor::setSpeed()` / `isRamping()` (Task 5); `MenuTab::onLongClick()` (Task 2)
  - `ticksToMm()` and `fitsDisplay()` from `calibration.h`
  - `Motor::start/stop/setMaxSpeed/getSpeed/isRunning`, `Motor::kDefaultRampMs`
  - `RotaryEncoder::getCount/reset`, `Max7219::printNumber/printText/clear`
- Produces: `struct WorkingContext { Max7219 &display; Motor &motor; RotaryEncoder &measure; const Settings &settings; int32_t target_mm; int32_t speed_percent; }` and `class WorkingMenu final : public Menu` with `explicit WorkingMenu(WorkingContext &ctx)`.

Page 4 is a small state machine. The *driving* states are `Running`, `SlowingDown` and `Creeping`. In every driving state, each pass checks these in order:
1. `shouldStop()` → stop, `Stopped`. The stop is **instant** (`setSpeed(0, 0)`) from `SlowingDown`/`Creeping`, and a normal ramped `stop()` from `Running`, where it only happens after an overshoot.
2. Stall → `stop()`, `Stalled`.
3. Otherwise, the state's own step from the table.

| State | Own step each pass | Long click |
|---|---|---|
| `Running` (motor at the max speed) | `shouldSlowDown()` → `creep_.start(estimateCreepPower(motor power, measured speed))`, `setSpeed(that power, kDefaultRampMs)`, `SlowingDown` | `stop()`, `Paused` |
| `SlowingDown` (ramping to the creep power) | ramp finished (`!isRamping()`) → `creep_.start(creep_.power())`, `Creeping` | `stop()`, `Paused` |
| `Creeping` (holding `kCreepSpeedMmPerS`) | `creep_.update(measured speed)`; if the power changed, `setSpeed(power, kCreepRampMs)` | `stop()`, `Paused` |
| `Paused` (blinks) | — | resume |
| `Stalled` (blinks) | — | resume |
| `Stopped` (target − 1 mm reached) | — | resume (does nothing: target reached) |

"Resume" works like this:
- If `shouldStop()`, go to `Stopped`.
- Otherwise reset `SpeedMeter` and `StallDetector`. Then:
  - if `shouldSlowDown(pulled, target, 0.0, …)` (no more than `kCreepMinMm` left), go straight to `Creeping` with the remembered `creep_.power()`;
  - else call `motor.start()` and go to `Running`.

For tuning, the creep phase prints the measured speed and power over USB serial (`printf`, stdio is USB CDC), and so does the stop.

- [ ] **Step 1: Create the header**

Create `Code/working_menu.h`:

```cpp
#pragma once

#include <stdint.h>

#include "menu.h"
#include "number_edit_tab.h"
#include "run_logic.h"
#include "settings.h"

class Max7219;
class Motor;
class RotaryEncoder;

// Hardware and state shared by the working pages. target_mm and
// speed_percent live in RAM: kept between runs, reset at power-up.
struct WorkingContext {
    Max7219 &display;
    Motor &motor;
    RotaryEncoder &measure;    // measuring-roll encoder
    const Settings &settings;  // mm_per_tick from the last calibration

    int32_t target_mm = kDefaultTargetMm;
    int32_t speed_percent = kDefaultSpeedPercent;
};

// Page 3: counting starts at 0, the motor stays off; the user threads the wire.
class RunThreadTab final : public MenuTab {
public:
    explicit RunThreadTab(WorkingContext &ctx) : ctx_(ctx) {}
    void onEnter() override;
    TabAction update(uint32_t now_ms) override;

private:
    WorkingContext &ctx_;
    int64_t shown_mm_ = -1;  // last value drawn, to redraw only on change
};

// Page 4: the motor pulls the wire, slows down to a creep speed near the
// target and stops at target - kStopBeforeMm. Long click pauses and resumes;
// the page only advances on a short click.
class RunPullTab final : public MenuTab {
public:
    explicit RunPullTab(WorkingContext &ctx) : ctx_(ctx) {}
    void onEnter() override;
    TabAction update(uint32_t now_ms) override;
    TabAction onLongClick() override;
    void onExit() override;

private:
    enum class State : uint8_t {
        Running,      // motor at the max speed
        SlowingDown,  // ramping down to the first guess of the creep power
        Creeping,     // holding the creep speed from the measured wire speed
        Paused,       // stopped by a long click (display blinks)
        Stalled,      // stopped: no wire movement for 10 s (display blinks)
        Stopped,      // target - kStopBeforeMm reached
    };

    bool isDriving() const;  // Running, SlowingDown or Creeping
    float maxPower() const;  // the user's max speed as motor power
    // The driving state's own step: start slowing down, finish slowing
    // down, or correct the creep power
    void steer(double speed_mm_per_s, int64_t mm, uint32_t now_ms);
    void creepAt(float power);
    // Starts the motor (or creeps, if close) unless the target is reached.
    void resume(int32_t count, int64_t mm, uint32_t now_ms);
    void draw(int64_t mm, uint32_t now_ms);

    WorkingContext &ctx_;
    State state_ = State::Stopped;
    bool start_pending_ = false;  // set by onEnter(); the start needs update()'s time
    SpeedMeter speed_;
    CreepController creep_;       // keeps its power between runs
    StallDetector stall_;
    float driven_power_ = 0.0f;   // last power given to the motor while creeping
    uint32_t now_ms_ = 0;         // time of the latest pass, for long clicks
    int64_t shown_mm_ = -1;
    bool shown_blank_ = false;
};

// Page 5: the final length. It follows the wire until the motor has fully
// stopped (the braking wire is real wire), then freezes: counting ends.
class RunDoneTab final : public MenuTab {
public:
    explicit RunDoneTab(WorkingContext &ctx) : ctx_(ctx) {}
    void onEnter() override;
    TabAction update(uint32_t now_ms) override;

private:
    WorkingContext &ctx_;
    int64_t shown_mm_ = -1;
    bool frozen_ = false;
};

// The working menu: length, speed, thread, pull, done.
class WorkingMenu final : public Menu {
public:
    explicit WorkingMenu(WorkingContext &ctx);

protected:
    void onClose() override;

private:
    WorkingContext &ctx_;
    NumberEditTab length_;  // page 1: target length in mm
    NumberEditTab speed_;   // page 2: max motor speed in %
    RunThreadTab thread_;
    RunPullTab pull_;
    RunDoneTab done_;
};
```

- [ ] **Step 2: Create the implementation**

Create `Code/working_menu.cpp`:

```cpp
#include "working_menu.h"

#include <stdio.h>

#include "calibration.h"
#include "max7219.h"
#include "motor.h"
#include "rotary_encoder.h"

namespace {

constexpr uint32_t kBlinkHalfPeriodMs = 500;
constexpr uint32_t kCreepRampMs = 100;  // smooths each creep power change

int64_t pulledMm(const WorkingContext &ctx, int32_t count) {
    return ticksToMm(count, ctx.settings.mm_per_tick);
}

void showPulledMm(Max7219 &display, int64_t mm) {
    if (fitsDisplay(mm)) {
        display.printNumber((int32_t)mm);
    } else {
        display.printText("--------");
    }
}

}  // namespace

// --- Page 3: thread the wire ---

void RunThreadTab::onEnter() {
    ctx_.measure.reset();  // counting starts now; the motor stays off
    shown_mm_ = -1;
}

TabAction RunThreadTab::update(uint32_t) {
    int64_t mm = pulledMm(ctx_, ctx_.measure.getCount());
    if (mm != shown_mm_) {
        shown_mm_ = mm;
        showPulledMm(ctx_.display, mm);
    }
    return TabAction::Stay;
}

// --- Page 4: pull ---

void RunPullTab::onEnter() {
    ctx_.motor.setMaxSpeed((uint8_t)ctx_.speed_percent);
    state_ = State::Stopped;
    start_pending_ = true;
    shown_mm_ = -1;
    shown_blank_ = false;
}

TabAction RunPullTab::update(uint32_t now_ms) {
    int32_t count = ctx_.measure.getCount();
    int64_t mm = pulledMm(ctx_, count);

    if (start_pending_) {
        start_pending_ = false;
        resume(count, mm, now_ms);
    }

    if (isDriving()) {
        double speed = speed_.update(mm, now_ms);
        if (shouldStop(mm, ctx_.target_mm)) {
            if (state_ == State::Running) {
                ctx_.motor.stop();  // overshot at full speed: brake gently
            } else {
                ctx_.motor.setSpeed(0.0f, 0);  // creeping: stop at once, the wire coasts ~1 mm
            }
            printf("stop: %lld mm pulled, target %ld mm\n", (long long)mm, (long)ctx_.target_mm);
            state_ = State::Stopped;
        } else if (stall_.update(count, now_ms)) {
            ctx_.motor.stop();
            state_ = State::Stalled;
        } else {
            steer(speed, mm, now_ms);
        }
    }

    draw(mm, now_ms);
    now_ms_ = now_ms;
    return TabAction::Stay;
}

void RunPullTab::steer(double speed_mm_per_s, int64_t mm, uint32_t now_ms) {
    switch (state_) {
        case State::Running:
            // Motor::kDefaultRampMs: Code.cpp builds the motor with the default ramp
            if (shouldSlowDown(mm, ctx_.target_mm, speed_mm_per_s, Motor::kDefaultRampMs)) {
                creep_.start(estimateCreepPower(ctx_.motor.getSpeed(), speed_mm_per_s), maxPower(), now_ms);
                driven_power_ = creep_.power();
                ctx_.motor.setSpeed(driven_power_, Motor::kDefaultRampMs);
                state_ = State::SlowingDown;
            }
            break;
        case State::SlowingDown:
            if (!ctx_.motor.isRamping()) {
                creep_.start(creep_.power(), maxPower(), now_ms);  // first adjustment one window later
                state_ = State::Creeping;
            }
            break;
        case State::Creeping: {
            float power = creep_.update(speed_mm_per_s, now_ms);
            if (power != driven_power_) {
                creepAt(power);
                // For tuning kCreep* over USB serial
                printf("creep: %.1f mm/s, power %.3f\n", speed_mm_per_s, (double)power);
            }
            break;
        }
        case State::Paused:
        case State::Stalled:
        case State::Stopped:
            break;
    }
}

TabAction RunPullTab::onLongClick() {
    if (isDriving()) {
        ctx_.motor.stop();
        state_ = State::Paused;
    } else {
        // now_ms_ is from the previous pass (<= one loop period old)
        int32_t count = ctx_.measure.getCount();
        resume(count, pulledMm(ctx_, count), now_ms_);
    }
    return TabAction::Stay;
}

void RunPullTab::onExit() {
    // Page 5 needs a stopped motor. Only the driving states still drive it:
    // the others already stopped it, and a second stop() would restart the ramp.
    if (isDriving()) ctx_.motor.stop();
    start_pending_ = false;
}

bool RunPullTab::isDriving() const {
    return state_ == State::Running || state_ == State::SlowingDown || state_ == State::Creeping;
}

float RunPullTab::maxPower() const {
    return ctx_.speed_percent / 100.0f;
}

void RunPullTab::creepAt(float power) {
    driven_power_ = power;
    ctx_.motor.setSpeed(power, kCreepRampMs);
}

void RunPullTab::resume(int32_t count, int64_t mm, uint32_t now_ms) {
    if (shouldStop(mm, ctx_.target_mm)) {  // nothing left to pull
        state_ = State::Stopped;
        return;
    }
    speed_.reset(mm, now_ms);
    stall_.reset(count, now_ms);
    if (shouldSlowDown(mm, ctx_.target_mm, 0.0, Motor::kDefaultRampMs)) {
        // Too close to speed up first: creep straight away, from the last
        // creep power (the best guess this machine has)
        creep_.start(creep_.power(), maxPower(), now_ms);
        creepAt(creep_.power());
        state_ = State::Creeping;
    } else {
        ctx_.motor.start();
        state_ = State::Running;
    }
}

void RunPullTab::draw(int64_t mm, uint32_t now_ms) {
    // Paused or stalled: blink, so it is clear the machine waits for a long click
    bool blinking = state_ == State::Paused || state_ == State::Stalled;
    bool blank = blinking && (now_ms / kBlinkHalfPeriodMs) % 2 == 1;
    if (blank == shown_blank_ && mm == shown_mm_) return;
    shown_blank_ = blank;
    shown_mm_ = mm;
    if (blank) {
        ctx_.display.clear();
    } else {
        showPulledMm(ctx_.display, mm);
    }
}

// --- Page 5: done ---

void RunDoneTab::onEnter() {
    // The motor was stopped by RunPullTab::onExit() and may still be braking
    shown_mm_ = -1;
    frozen_ = false;
}

TabAction RunDoneTab::update(uint32_t) {
    if (frozen_) return TabAction::Stay;
    int64_t mm = pulledMm(ctx_, ctx_.measure.getCount());
    if (mm != shown_mm_) {
        shown_mm_ = mm;
        showPulledMm(ctx_.display, mm);
    }
    if (!ctx_.motor.isRunning()) frozen_ = true;  // counting ends here
    return TabAction::Stay;
}

// --- Menu ---

WorkingMenu::WorkingMenu(WorkingContext &ctx)
    : ctx_(ctx),
      length_(ctx.display, ctx.target_mm, kMinTargetMm, kMaxTargetMm, 1000),
      speed_(ctx.display, ctx.speed_percent, kMinSpeedPercent, kMaxSpeedPercent, 10, "SP"),
      thread_(ctx), pull_(ctx), done_(ctx) {
    addTab(length_);
    addTab(speed_);
    addTab(thread_);
    addTab(pull_);
    addTab(done_);
}

void WorkingMenu::onClose() {
    // Safety net, whichever way the menu closes; only if actually needed, so
    // this does not start a pointless 0->0 ramp on an already-stopped motor.
    if (ctx_.motor.isRunning()) ctx_.motor.stop();
    // Calibration runs the motor with start() too: give it back full speed.
    // Not running (stop() above cleared that), so this only stores the value.
    ctx_.motor.setMaxSpeed(kMaxSpeedPercent);
}
```

- [ ] **Step 3: Wire it into the firmware**

In `Code/CMakeLists.txt`, extend the source list to:

```cmake
add_executable(Code Code.cpp max7219.cpp rotary_encoder.cpp motor.cpp
        click_detector.cpp menu.cpp menu_manager.cpp knob_accel.cpp settings.cpp calibration.cpp settings_store.cpp calibration_menu.cpp
        number_edit_tab.cpp run_logic.cpp working_menu.cpp)
```

In `Code/Code.cpp`:
- Add `#include "working_menu.h"` after `#include "calibration_menu.h"`.
- In the anonymous namespace, delete the `LabelTab` class with its `// PLACEHOLDER tab ...` comment, the two lines `LabelTab workTab1("run 1");` and `LabelTab workTab2("run 2");`, and the line `Menu workingMenu;`.
- Directly after `Settings settings;  // loaded from flash in main(); the calibration menu updates it`, add:

```cpp
WorkingContext working{display, motor, measureEncoder, settings};
WorkingMenu workingMenu(working);
```

- In `main()`, delete the two lines `workingMenu.addTab(workTab1);` and `workingMenu.addTab(workTab2);`.

- [ ] **Step 4: Build and run the tests**

Run: `~/.pico-sdk/ninja/v1.13.2/ninja -C Code/build` → Expected: builds without errors.
Run: `Code/tests/run_tests.sh` → Expected: `All tests passed`.
Run: `grep -n "LabelTab\|workTab" Code/Code.cpp` → Expected: no output.

- [ ] **Step 5: Hardware check** (flash with `picotool load Code/build/Code.elf -fx`. If the board is not on USB: BOOTSEL + reflash. Keep a serial monitor open on the USB port to see the `creep:` / `stop:` lines.)

Walk through the checklist and write down every mismatch:
1. User-knob click: the display shows `1000`. Turn slowly (±1), faster (±10 / ±100), and very fast (±1000). The value stays within 1 … 99999999.
2. Click: `SP   100`. Turning moves it by 1 or 10, and it stays within 1 … 100. Set 50.
3. Click: `0`. The motor is off. Pull some wire by hand: the number grows.
4. Click: the motor starts at about half speed, and the number grows.
   - Long click (hold > 2 s, release): the motor brakes and the number blinks. Pull the wire by hand: it still counts.
   - Long click again: the motor resumes.
   - Hold the wire so the roll does not turn: after 10 s the motor stops and the number blinks. A long click resumes.
   - Let it run. It should slow down before the target, creep, and stop at once at target − 1 mm.
     - The serial log shows the `creep:` speed settling near `kCreepSpeedMmPerS`.
     - Write down the final number on the display and the `stop:` line, for tuning the `kCreep*` constants.
5. Click: the number freezes once the motor has stopped. Click: idle screen (all segments lit).
6. Open the working menu again: page 1 shows the last target, page 2 shows `SP    50`.
7. Set a target of 10 mm and run it: there is no fast phase; the motor creeps straight away and stops at 9 mm.
8. Measuring-encoder click: calibration page 1 still behaves as before, and its motor starts and stops with the same smooth 2.5 s ramps at full speed.
9. Mid-run, while the motor is running, short-click on page 4: the motor brakes, page 5 follows the braking wire and then freezes.

**Tuning order** (write the values found into `run_logic.h`, then run `Code/tests/run_tests.sh` again):
1. `kCreepSpeedMmPerS`: the slowest speed at which the motor still turns smoothly, from the `creep:` lines.
2. `kCreepGainPerMmS`: raise it if the speed settles too slowly, lower it if the speed swings.
3. `kCreepMinMm`: make it long enough that the speed has settled before the stop.
4. `kCreepMinPower` and the initial `CreepController::power_`: the power at which the motor just keeps turning.

- [ ] **Step 6: Commit**

```bash
git add Code/working_menu.h Code/working_menu.cpp Code/Code.cpp Code/CMakeLists.txt
git commit -m "feat(firmware): real working menu with pause, stall stop and creep landing" -- Code/working_menu.h Code/working_menu.cpp Code/Code.cpp Code/CMakeLists.txt
```

---

### Task 8: Documentation

**Files:**
- Modify: `Code/CLAUDE.md`
- Create: `Instructions/working.md`

**Interfaces:** none (docs only).

- [ ] **Step 1: Update `Code/CLAUDE.md`**

Make these edits:
- In the `Code.cpp` bullet, replace `The Working menu's `LabelTab`s are still placeholders.` with `It builds the Working menu from a `WorkingContext` and the Calibration menu from a `CalibrationContext`.`
- Replace the `click_detector.{h,cpp}` bullet with:
  `` - `click_detector.{h,cpp}` — `ClickDetector`: on release reports `ClickEvent::Short` (held ≤ 2 s, `kShortClickMaxMs`) or `ClickEvent::Long` (held longer); nothing while held. User-knob long clicks reach the shown tab via `MenuInput::user_long_click` → `MenuTab::onLongClick()` (default: ignored) and never open a menu. ``
- At the end of the `motor.{h,cpp}` bullet, add: `` `setSpeed(speed, ramp_ms)` drives an exact power (not limited by the max speed) with its own ramp time, 0 = at once; `isRamping()` tells when a ramp has finished. ``
- In the `KnobAccel` mention in the Calibration bullet, change `is 1/10/100 mm depending on turning speed` to `is 1/10/100 mm depending on turning speed (`KnobAccel(max_factor)` caps the step; the working menu's length uses 1000)`.
- Add a new bullet after the Calibration bullet:

```markdown
- Working menu (`run_logic.{h,cpp}` = pure maths, host-tested; `working_menu.{h,cpp}` = pages; `number_edit_tab.{h,cpp}` = generic knob-edited number page, also calibration page 1): target length in mm (1 … 99 999 999, step up to ×1000) → max speed `SP` 1 … 100 % → thread (counting from 0, motor off) → pull → done. Target and speed are kept in RAM only (defaults after power-up), never written to flash. Pull page: long click pauses/resumes (counting continues); no movement of ≥ 4 ticks for 10 s while driving stops the motor (`StallDetector`); paused/stalled blinks. Landing: once `pulled + (speed + kCreepSpeedMmPerS) / 2 × ramp + kCreepMinMm ≥ target` (`SpeedMeter` over 100 ms, `Motor::kDefaultRampMs`), the motor ramps to a first-guess creep power (power × creep / speed); `CreepController` then corrects the power every 100 ms from the measured speed, and at `target − kStopBeforeMm` (1 mm) the motor stops at once via `Motor::setSpeed(0, 0)`. Within `kCreepMinMm` of the target it creeps from the start. The `kCreep*` constants in `run_logic.h` are first guesses (marked TUNE); the creep phase prints `creep:` / `stop:` lines over USB serial for tuning. Done page follows the wire until the motor has stopped, then freezes. `WorkingMenu::onClose()` resets the motor max speed to 100 % for calibration.
```

- [ ] **Step 2: Write the user instructions**

Create `Instructions/working.md`:

```markdown
# Winding a hank of wire

Calibrate the machine first (see `calibration.md`), and again whenever you change to a different wire.

## Run

1. **Start:** click the **user knob**.
2. **Length:** turn the knob until the display shows the length you want, in mm.
   - Turn slowly for 1 mm steps, and faster for 10, 100 or 1000 mm steps.
   - Click.
3. **Speed:** the display shows `SP` and the maximum motor speed in percent (100 = full speed). Turn to change it, then click.
4. **Thread the wire:** the display shows `0`, and the motor stays off.
   1. Put the wire through the measuring roll and tie it to the motor. The display already counts the wire that goes through.
   2. Click. The motor starts.
5. **Pulling:** the display shows how much wire has passed.
   - **Pause:** hold the knob for more than 2 s, then release. The motor stops and the number blinks. The wire is still counted if you move it by hand.
   - **Continue:** hold for more than 2 s and release again.
   - Shortly before the target, the motor slows down to a crawl by itself and stops right at the target.
   - If the wire does not move for 10 s while the motor runs (for example, it is stuck), the motor stops and the number blinks. Fix the problem, then hold and release to continue.
   - Click when you are done. You can do this at any time; it also stops the motor.
6. **Result:** the display shows the final length once the motor has stopped. Click to finish.

The next run starts with the same length and speed, until the machine is switched off.
```

- [ ] **Step 3: Commit**

```bash
git add Code/CLAUDE.md Instructions/working.md
git commit -m "docs: document the working menu" -- Code/CLAUDE.md Instructions/working.md
```

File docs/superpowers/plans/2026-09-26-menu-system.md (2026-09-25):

# Menu System Implementation Plan

> **For agentic workers:** REQUIRED SUB-SKILL: Use superpowers:subagent-driven-development (recommended) or superpowers:executing-plans to implement this plan task-by-task. Steps use checkbox (`- [ ]`) syntax for tracking.

**Goal:** Build a menu framework for the firmware. The two menus it has to support are Working and Calibration. Each menu is a fixed sequence of tabs, a short click on the user encoder advances to the next tab, only one menu can be open at a time, and after power-up the display lights all segments without opening a menu.

**Architecture:** There are three small classes, and none of them depends on the hardware:
- `ClickDetector` turns the debounced button level into "short click" events. A press counts only if it is released within 2 s.
- `Menu` holds an ordered list of `MenuTab` pages and walks through them.
- `MenuManager` binds each menu to the event that opens it. It lets only one menu be active, routes the user-encoder input to the active menu, and shows the idle screen when that menu closes.

`Code.cpp` wires these classes to the real encoders and the display. The real menus are not part of this plan. It registers only two placeholder menus, each with two label tabs, so the flow can be checked on the hardware.

**Tech Stack:** C++17, Raspberry Pi Pico SDK 2.3.1 (RP2350B, Ninja build), host-side unit tests compiled with the system `g++` (no test framework, a 10-line `CHECK` macro).

## Global Constraints

- The menu core (`click_detector.*`, `menu.*`, `menu_manager.*`) must not include any Pico SDK header. Only `<stdint.h>` is allowed, so the same files compile for the host tests and for the firmware.
- No heap in the firmware path: no `new`, `std::function`, `std::vector` or `std::string`. Fixed-size arrays and plain function pointers only.
- A short click is a press released **≤ 2000 ms** after it started (`ClickDetector::kShortClickMaxMs = 2000`). A longer press does nothing.
- In **both** menus, the next tab is selected by a short click on the **user** encoder.
- The Working menu opens on a short click of the user encoder. The Calibration menu opens on a short click of the measuring-roll encoder.
- Only one menu is open at a time. While a menu is open, the event that opens the other menu is **ignored**. A click never closes one menu and opens another.
- After power-up the display shows every segment and dot lit (idle screen), and no menu opens until the matching click. The display returns to this idle screen whenever a menu closes.
- The code style matches the existing firmware: `snake_case_` members, `camelCase()` methods, `kConstant` constants, 4-space indent, `#pragma once`, and the `// comment` density used in `motor.cpp` and `rotary_encoder.cpp`.
- Every new firmware `.cpp` file must be added to `add_executable(Code ...)` in `Code/CMakeLists.txt`.
- Do not edit the `DO NOT EDIT` block in `Code/CMakeLists.txt`.

## File Structure

All paths are relative to the repository root. The firmware keeps its existing flat layout in `Code/`.

| File | Responsibility |
|---|---|
| `Code/click_detector.{h,cpp}` (create) | Short-click detection from the button level and a millisecond timestamp |
| `Code/menu.{h,cpp}` (create) | `MenuTab` interface, `TabAction`, and `Menu`, which walks the tabs of one menu |
| `Code/menu_manager.{h,cpp}` (create) | `MenuInput`, `MenuTrigger`, and `MenuManager`, which opens menus on their trigger, keeps them mutually exclusive, and shows the idle screen |
| `Code/tests/check.h` (create) | `CHECK` macro and failure counter |
| `Code/tests/test_main.cpp` (create) | Runs all test suites and returns non-zero on failure |
| `Code/tests/test_click_detector.cpp`, `test_menu.cpp`, `test_menu_manager.cpp` (create) | One suite per class |
| `Code/tests/fake_tab.h` (create) | `FakeTab`, which records calls for the menu tests |
| `Code/tests/run_tests.sh` (create) | Compiles and runs the host tests |
| `Code/Code.cpp` (modify) | Replaces the motor test loop with the menu manager, the placeholder menus and the idle screen |
| `Code/CMakeLists.txt` (modify) | Adds the new sources |
| `Code/CLAUDE.md` (modify) | Documents the menu system, how to add a menu, and how to run the tests |
| `.gitignore` (modify) | Ignores `Code/tests/build/` |

---

### Task 1: Test harness + `ClickDetector`

**Files:**
- Create: `Code/tests/check.h`, `Code/tests/test_main.cpp`, `Code/tests/run_tests.sh`, `Code/tests/test_click_detector.cpp`
- Create: `Code/click_detector.h`, `Code/click_detector.cpp`
- Modify: `.gitignore`

**Interfaces:**
- Consumes: none.
- Produces:
  - `class ClickDetector { static constexpr uint32_t kShortClickMaxMs = 2000; explicit ClickDetector(uint32_t max_short_ms = kShortClickMaxMs); bool update(bool pressed, uint32_t now_ms); }`
  - `Code/tests/check.h` provides `CHECK(cond)` and `inline int g_failures`.
  - `Code/tests/run_tests.sh` compiles `Code/tests/test_*.cpp` plus the core sources listed in its `SOURCES` variable. Later tasks append to `SOURCES`.

- [ ] **Step 0: Commit the existing firmware baseline (only if `Code/` is still untracked)**

The whole `Code/` directory is untracked at the moment. Commit it first so that the menu work shows up as clean diffs. The pathspec commits only `Code/` and leaves the unrelated staged changes (the Case/PCB files) alone:

```bash
cd /home/leonid/Documents/hardware_projects/wire_counting_machine
git status --short Code | head -3        # "?? Code/" means untracked, so run the next two commands
git add Code
git commit -m "chore(firmware): add existing firmware (display, encoders, motor)" -- Code
```

`Code/build/` and `.vscode` are already listed in `.gitignore`, so they stay out of the commit. Confirm with `git show --stat HEAD | grep -c build/`, which should print `0`.

- [ ] **Step 1: Create the test harness**

`Code/tests/check.h`:

```cpp
#pragma once

#include <cstdio>

// Minimal test helper: counts failures and keeps going, so one run reports
// every broken check.
inline int g_failures = 0;

#define CHECK(cond)                                                          \
    do {                                                                     \
        if (!(cond)) {                                                       \
            std::printf("%s:%d: CHECK failed: %s\n", __FILE__, __LINE__, #cond); \
            g_failures++;                                                    \
        }                                                                    \
    } while (0)
```

`Code/tests/test_main.cpp`:

```cpp
#include <cstdio>

#include "check.h"

void runClickDetectorTests();

int main() {
    runClickDetectorTests();

    if (g_failures != 0) {
        std::printf("%d check(s) failed\n", g_failures);
        return 1;
    }
    std::printf("All tests passed\n");
    return 0;
}
```

`Code/tests/run_tests.sh`:

```sh
#!/bin/sh
# Host-side unit tests for the hardware-independent firmware logic.
set -e
cd "$(dirname "$0")"
mkdir -p build

SOURCES="../click_detector.cpp"

g++ -std=c++17 -Wall -Wextra -Werror -I.. -o build/tests test_*.cpp $SOURCES
./build/tests
```

Then make it executable and ignore the build output:

```bash
chmod +x Code/tests/run_tests.sh
echo '/Code/tests/build/' >> .gitignore
```

- [ ] **Step 2: Write the failing tests**

`Code/tests/test_click_detector.cpp`:

```cpp
#include "check.h"
#include "click_detector.h"

namespace {

void testNoPressNoClick() {
    ClickDetector d;
    CHECK(!d.update(false, 0));
    CHECK(!d.update(false, 100));
}

void testShortPressClicksOnceOnRelease() {
    ClickDetector d;
    CHECK(!d.update(true, 1000));   // pressed: nothing yet
    CHECK(!d.update(true, 1100));   // still held
    CHECK(d.update(false, 1150));   // released after 150 ms: click
    CHECK(!d.update(false, 1200));  // reported only once
}

void testPressExactlyAtLimitIsShort() {
    ClickDetector d;
    d.update(true, 0);
    CHECK(d.update(false, ClickDetector::kShortClickMaxMs));
}

void testLongPressIsIgnored() {
    ClickDetector d;
    d.update(true, 0);
    CHECK(!d.update(true, 1000));
    CHECK(!d.update(false, ClickDetector::kShortClickMaxMs + 1));
}

void testCustomLimit() {
    ClickDetector d(500);
    d.update(true, 0);
    CHECK(!d.update(false, 600));  // 600 ms > 500 ms: too long
    d.update(true, 1000);
    CHECK(d.update(false, 1400));  // 400 ms: short
}

void testMillisecondCounterWraparound() {
    ClickDetector d;
    d.update(true, 0xFFFFFF00u);    // 256 ms before the uint32_t wrap
    CHECK(d.update(false, 100));    // 356 ms later
}

}  // namespace

void runClickDetectorTests() {
    testNoPressNoClick();
    testShortPressClicksOnceOnRelease();
    testPressExactlyAtLimitIsShort();
    testLongPressIsIgnored();
    testCustomLimit();
    testMillisecondCounterWraparound();
}
```

- [ ] **Step 3: Run the tests to verify they fail**

Run: `Code/tests/run_tests.sh`
Expected: the compile fails with `click_detector.h: No such file or directory`.

- [ ] **Step 4: Write the implementation**

`Code/click_detector.h`:

```cpp
#pragma once

#include <stdint.h>

// Turns a debounced button level into "short click" events.
//
// A click is reported once, on release, and only if the button was held for
// at most max_short_ms. Longer presses are ignored, so leaning on the knob
// does not flip menu pages. Pure logic (no SDK calls), so it is unit-tested
// on the host; the caller passes the time in.
class ClickDetector {
public:
    static constexpr uint32_t kShortClickMaxMs = 2000;

    explicit ClickDetector(uint32_t max_short_ms = kShortClickMaxMs);

    // Call regularly with the current button state and time. Returns true
    // exactly once per short click. now_ms may wrap around.
    bool update(bool pressed, uint32_t now_ms);

private:
    uint32_t max_short_ms_;
    bool was_pressed_ = false;
    uint32_t press_start_ms_ = 0;
};
```

`Code/click_detector.cpp`:

```cpp
#include "click_detector.h"

ClickDetector::ClickDetector(uint32_t max_short_ms) : max_short_ms_(max_short_ms) {}

bool ClickDetector::update(bool pressed, uint32_t now_ms) {
    if (pressed && !was_pressed_) press_start_ms_ = now_ms;

    // Unsigned subtraction keeps the duration right across a counter wrap
    bool click = !pressed && was_pressed_ &&
                 (uint32_t)(now_ms - press_start_ms_) <= max_short_ms_;
    was_pressed_ = pressed;
    return click;
}
```

- [ ] **Step 5: Run the tests to verify they pass**

Run: `Code/tests/run_tests.sh`
Expected: `All tests passed`, exit code 0.

- [ ] **Step 6: Commit**

```bash
git add .gitignore Code/click_detector.h Code/click_detector.cpp Code/tests
git commit -m "feat(firmware): add short-click detector and host test harness

Constraint: menu pages must only turn on a short click (<= 2 s)
Confidence: high
Scope-risk: narrow

Co-Authored-By: Claude Opus 5.5 <noreply@anthropic.com>" -- .gitignore Code/click_detector.h Code/click_detector.cpp Code/tests
```

---

### Task 2: `MenuTab` + `Menu`

**Files:**
- Create: `Code/menu.h`, `Code/menu.cpp`
- Create: `Code/tests/fake_tab.h`, `Code/tests/test_menu.cpp`
- Modify: `Code/tests/test_main.cpp`, `Code/tests/run_tests.sh`

**Interfaces:**
- Consumes: the `CHECK` harness from Task 1.
- Produces:
  - `enum class TabAction : uint8_t { Stay, Next, CloseMenu };`
  - `class MenuTab`, with virtual hooks and these defaults: `void onEnter()`, `void onTurn(int32_t detents)`, `TabAction onClick()` (default `Next`), `TabAction update(uint32_t now_ms)` (default `Stay`), `void onExit()`. Its destructor is protected and non-virtual.
  - `class Menu { static constexpr int kMaxTabs = 8; bool addTab(MenuTab &tab); int tabCount() const; void open(); void close(); bool isOpen() const; int currentTab() const /* -1 when closed */; void turn(int32_t detents); void click(); void update(uint32_t now_ms); protected: virtual void onOpen(); virtual void onClose(); }`
  - `Code/tests/fake_tab.h` provides `FakeTab` with public counters `enters`, `exits`, `clicks`, `turned` and the settable fields `click_action` and `update_action`.

- [ ] **Step 1: Write the fake tab and the failing tests**

`Code/tests/fake_tab.h`:

```cpp
#pragma once

#include "menu.h"

// Records every call from the menu and returns configurable actions.
class FakeTab final : public MenuTab {
public:
    int enters = 0;
    int exits = 0;
    int clicks = 0;
    int32_t turned = 0;
    TabAction click_action = TabAction::Next;
    TabAction update_action = TabAction::Stay;

    void onEnter() override { enters++; }
    void onTurn(int32_t detents) override { turned += detents; }
    TabAction onClick() override { clicks++; return click_action; }
    TabAction update(uint32_t) override { return update_action; }
    void onExit() override { exits++; }
};
```

`Code/tests/test_menu.cpp`:

```cpp
#include "check.h"
#include "fake_tab.h"
#include "menu.h"

namespace {

class HookMenu final : public Menu {
public:
    int opens = 0;
    int closes = 0;

protected:
    void onOpen() override { opens++; }
    void onClose() override { closes++; }
};

void testOpenEntersFirstTab() {
    FakeTab a, b;
    Menu m;
    m.addTab(a);
    m.addTab(b);
    CHECK(!m.isOpen());
    CHECK(m.currentTab() == -1);

    m.open();
    CHECK(m.isOpen());
    CHECK(m.currentTab() == 0);
    CHECK(a.enters == 1);
    CHECK(b.enters == 0);

    m.open();  // already open: no restart
    CHECK(a.enters == 1);
}

void testClickNextAdvances() {
    FakeTab a, b;
    Menu m;
    m.addTab(a);
    m.addTab(b);
    m.open();
    m.click();
    CHECK(a.clicks == 1);
    CHECK(a.exits == 1);
    CHECK(b.enters == 1);
    CHECK(m.currentTab() == 1);
}

void testClickOnLastTabCloses() {
    FakeTab a, b;
    HookMenu m;
    m.addTab(a);
    m.addTab(b);
    m.open();
    m.click();
    m.click();
    CHECK(!m.isOpen());
    CHECK(m.currentTab() == -1);
    CHECK(b.exits == 1);
    CHECK(m.opens == 1);
    CHECK(m.closes == 1);
}

void testStayKeepsTab() {
    FakeTab a, b;
    a.click_action = TabAction::Stay;
    Menu m;
    m.addTab(a);
    m.addTab(b);
    m.open();
    m.click();
    CHECK(m.currentTab() == 0);
    CHECK(a.exits == 0);
    CHECK(b.enters == 0);
}

void testCloseMenuFromMiddleTab() {
    FakeTab a, b;
    a.click_action = TabAction::CloseMenu;
    HookMenu m;
    m.addTab(a);
    m.addTab(b);
    m.open();
    m.click();
    CHECK(!m.isOpen());
    CHECK(a.exits == 1);
    CHECK(b.enters == 0);
    CHECK(m.closes == 1);
}

void testUpdateCanAdvance() {
    FakeTab a, b;
    Menu m;
    m.addTab(a);
    m.addTab(b);
    m.open();
    m.update(10);
    CHECK(m.currentTab() == 0);  // default update() stays
    a.update_action = TabAction::Next;
    m.update(20);
    CHECK(m.currentTab() == 1);
}

void testTurnGoesToCurrentTabOnly() {
    FakeTab a, b;
    Menu m;
    m.addTab(a);
    m.addTab(b);
    m.open();
    m.turn(3);
    m.turn(-1);
    CHECK(a.turned == 2);
    CHECK(b.turned == 0);
    m.click();
    m.turn(5);
    CHECK(a.turned == 2);
    CHECK(b.turned == 5);
}

void testClosedMenuIgnoresInput() {
    FakeTab a;
    HookMenu m;
    m.addTab(a);
    m.click();
    m.turn(2);
    m.update(0);
    m.close();
    CHECK(a.clicks == 0);
    CHECK(a.turned == 0);
    CHECK(a.enters == 0);
    CHECK(a.exits == 0);
    CHECK(m.closes == 0);
}

void testExplicitClose() {
    FakeTab a, b;
    HookMenu m;
    m.addTab(a);
    m.addTab(b);
    m.open();
    m.close();
    CHECK(!m.isOpen());
    CHECK(a.exits == 1);
    CHECK(m.closes == 1);
}

void testReopenStartsAtFirstTab() {
    FakeTab a, b;
    Menu m;
    m.addTab(a);
    m.addTab(b);
    m.open();
    m.click();
    m.close();
    m.open();
    CHECK(m.currentTab() == 0);
    CHECK(a.enters == 2);
}

void testTabLimit() {
    FakeTab tabs[Menu::kMaxTabs + 1];
    Menu m;
    for (int i = 0; i < Menu::kMaxTabs; i++) CHECK(m.addTab(tabs[i]));
    CHECK(!m.addTab(tabs[Menu::kMaxTabs]));
    CHECK(m.tabCount() == Menu::kMaxTabs);
}

void testEmptyMenuClosesImmediately() {
    HookMenu m;
    m.open();
    CHECK(!m.isOpen());
    CHECK(m.opens == 1);
    CHECK(m.closes == 1);
}

}  // namespace

void runMenuTests() {
    testOpenEntersFirstTab();
    testClickNextAdvances();
    testClickOnLastTabCloses();
    testStayKeepsTab();
    testCloseMenuFromMiddleTab();
    testUpdateCanAdvance();
    testTurnGoesToCurrentTabOnly();
    testClosedMenuIgnoresInput();
    testExplicitClose();
    testReopenStartsAtFirstTab();
    testTabLimit();
    testEmptyMenuClosesImmediately();
}
```

Replace `Code/tests/test_main.cpp` with:

```cpp
#include <cstdio>

#include "check.h"

void runClickDetectorTests();
void runMenuTests();

int main() {
    runClickDetectorTests();
    runMenuTests();

    if (g_failures != 0) {
        std::printf("%d check(s) failed\n", g_failures);
        return 1;
    }
    std::printf("All tests passed\n");
    return 0;
}
```

In `Code/tests/run_tests.sh`, change the `SOURCES` line to:

```sh
SOURCES="../click_detector.cpp ../menu.cpp"
```

- [ ] **Step 2: Run the tests to verify they fail**

Run: `Code/tests/run_tests.sh`
Expected: the compile fails with `menu.h: No such file or directory`.

- [ ] **Step 3: Write the implementation**

`Code/menu.h`:

```cpp
#pragma once

#include <stdint.h>

// What a tab asks the menu to do after handling an event.
enum class TabAction : uint8_t {
    Stay,       // keep showing this tab
    Next,       // go to the next tab (closes the menu after the last one)
    CloseMenu,  // close the whole menu now
};

// One page of a menu. Subclass it and override only what the page needs;
// every hook has a sensible default. Tabs draw themselves (they keep their
// own reference to the display), so the menu core stays hardware-free.
class MenuTab {
public:
    // The tab became visible: draw it.
    virtual void onEnter() {}

    // The user encoder turned by `detents` (positive = clockwise).
    virtual void onTurn(int32_t detents) { (void)detents; }

    // Short click on the user encoder. Default: go to the next tab.
    virtual TabAction onClick() { return TabAction::Next; }

    // Called every main-loop pass while the tab is shown, for tabs that
    // react to something other than the knob (e.g. wire length reached).
    virtual TabAction update(uint32_t now_ms) { (void)now_ms; return TabAction::Stay; }

    // The tab is about to be hidden (next tab or menu closing).
    virtual void onExit() {}

protected:
    // Tabs are never deleted through a MenuTab pointer (no heap).
    ~MenuTab() = default;
};

// An ordered sequence of tabs: open -> tab 0 -> tab 1 -> ... -> close.
// Subclass and override onOpen() / onClose() for menu-wide setup and
// cleanup (e.g. stopping the motor when the working menu closes).
class Menu {
public:
    static constexpr int kMaxTabs = 8;

    // Appends a tab. Tabs are shown in the order they are added.
    // Returns false if the menu already has kMaxTabs tabs.
    bool addTab(MenuTab &tab);
    int tabCount() const;

    // Shows the first tab. Does nothing if the menu is already open.
    void open();

    // Hides the current tab and closes the menu. Safe to call when closed.
    void close();

    bool isOpen() const;

    // Index of the shown tab, -1 when closed.
    int currentTab() const;

    // Input for the shown tab; ignored while closed.
    void turn(int32_t detents);
    void click();
    void update(uint32_t now_ms);

protected:
    virtual void onOpen() {}
    virtual void onClose() {}

private:
    void apply(TabAction action);

    MenuTab *tabs_[kMaxTabs] = {};
    int tab_count_ = 0;
    int current_ = -1;
};
```

`Code/menu.cpp`:

```cpp
#include "menu.h"

bool Menu::addTab(MenuTab &tab) {
    if (tab_count_ >= kMaxTabs) return false;
    tabs_[tab_count_++] = &tab;
    return true;
}

int Menu::tabCount() const {
    return tab_count_;
}

void Menu::open() {
    if (isOpen()) return;
    onOpen();
    if (tab_count_ == 0) {  // nothing to show: open and close right away
        onClose();
        return;
    }
    current_ = 0;
    tabs_[current_]->onEnter();
}

void Menu::close() {
    if (!isOpen()) return;
    tabs_[current_]->onExit();
    current_ = -1;
    onClose();
}

bool Menu::isOpen() const {
    return current_ >= 0;
}

int Menu::currentTab() const {
    return current_;
}

void Menu::turn(int32_t detents) {
    if (isOpen() && detents != 0) tabs_[current_]->onTurn(detents);
}

void Menu::click() {
    if (isOpen()) apply(tabs_[current_]->onClick());
}

void Menu::update(uint32_t now_ms) {
    if (isOpen()) apply(tabs_[current_]->update(now_ms));
}

void Menu::apply(TabAction action) {
    if (!isOpen()) return;  // the tab may have closed the menu itself
    switch (action) {
        case TabAction::Stay:
            break;
        case TabAction::Next:
            if (current_ + 1 >= tab_count_) {
                close();
                break;
            }
            tabs_[current_]->onExit();
            current_++;
            tabs_[current_]->onEnter();
            break;
        case TabAction::CloseMenu:
            close();
            break;
    }
}
```

- [ ] **Step 4: Run the tests to verify they pass**

Run: `Code/tests/run_tests.sh`
Expected: `All tests passed`, exit code 0.

- [ ] **Step 5: Commit**

```bash
git add Code/menu.h Code/menu.cpp Code/tests
git commit -m "feat(firmware): add Menu and MenuTab page sequence

Rejected: std::function callbacks per tab | pulls in heap on the RP2350
Confidence: high
Scope-risk: narrow

Co-Authored-By: Claude Opus 5.5 <noreply@anthropic.com>" -- Code/menu.h Code/menu.cpp Code/tests
```

---
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

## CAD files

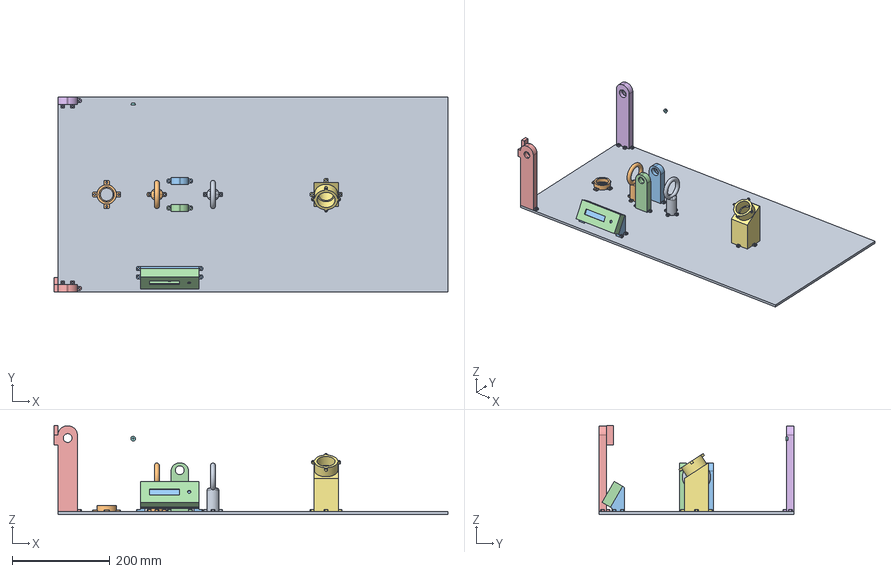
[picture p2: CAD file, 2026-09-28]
Case/Assembly.FCStd
808.1 x 400.0 x 183.0 mm
bottom_plane
Bearing_case
bottom_roll_placement1
bottom_roll_placement2
top_roll_placement1
top_roll_placement2
motor_placement
washer_4_3_10
string_pass2
string_pass1
display_stand

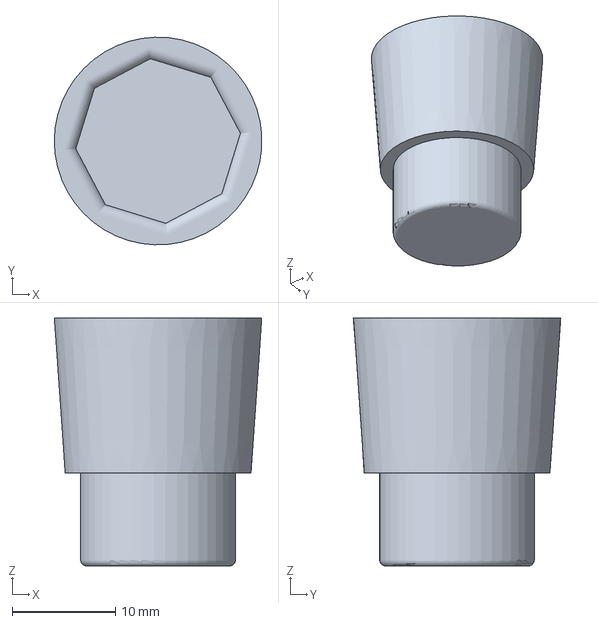
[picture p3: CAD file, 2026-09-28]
Case/string_roll_adapter.3mf
20.1 x 20.1 x 24.0 mm

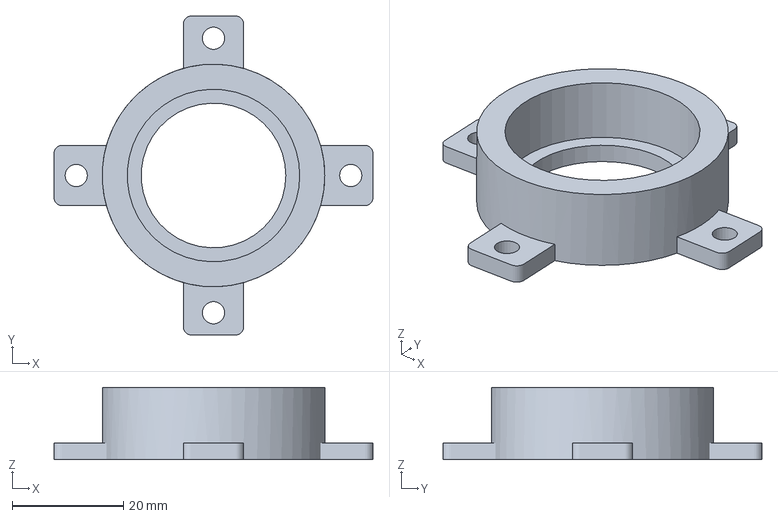
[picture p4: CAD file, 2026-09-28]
Case/Bearing_case.3mf
57.3 x 57.3 x 13.0 mm

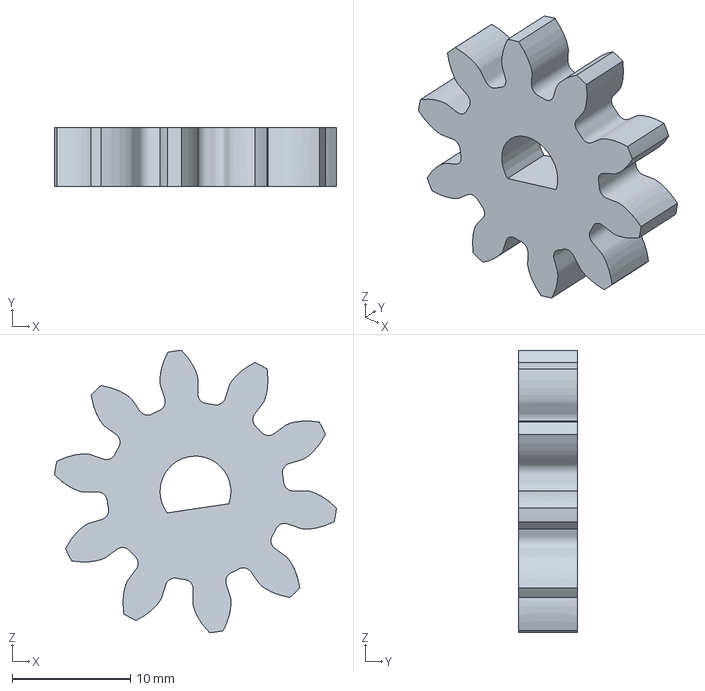
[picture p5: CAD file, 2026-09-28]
Case/encoder_gear.3mf
23.8 x 5.00 x 23.9 mm

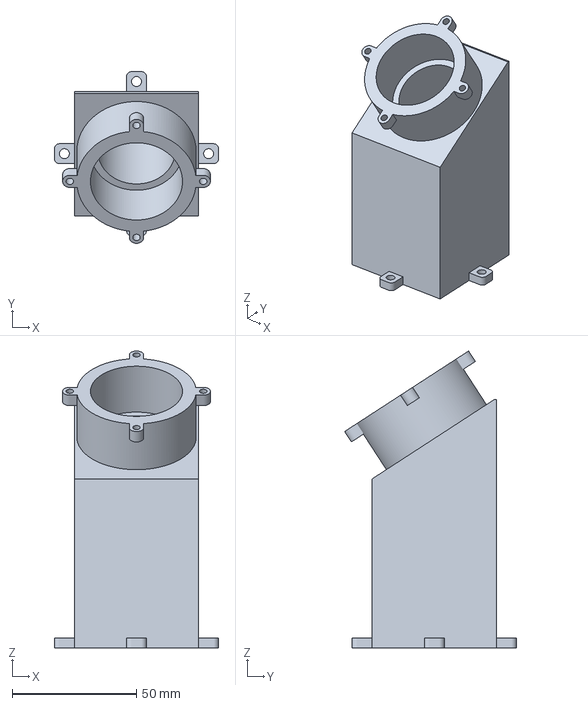
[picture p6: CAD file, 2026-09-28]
Case/motor_placement.3mf
66.0 x 69.1 x 119.4 mm

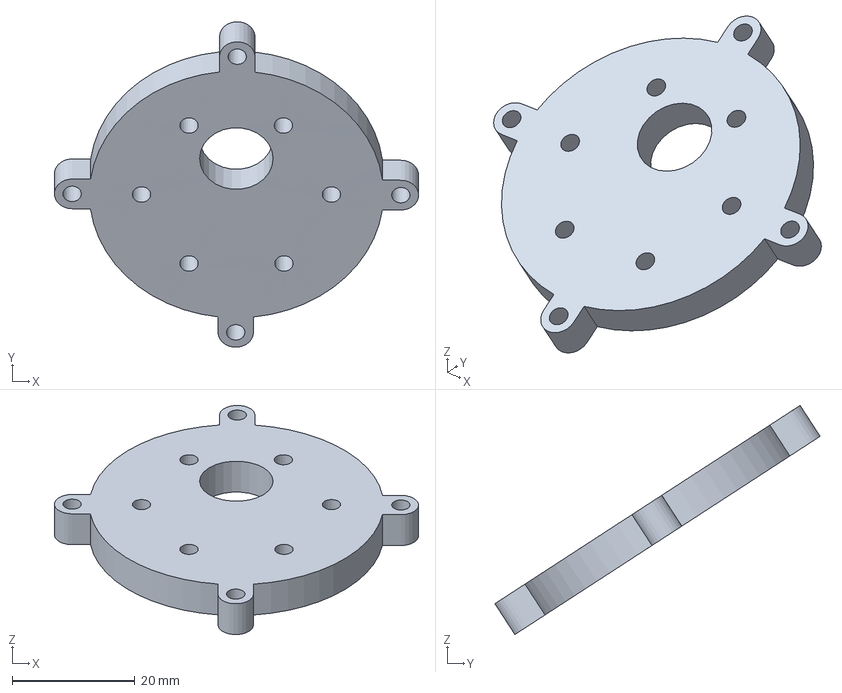
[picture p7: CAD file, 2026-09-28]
Case/motor_fixer.3mf
59.4 x 53.1 x 37.4 mm

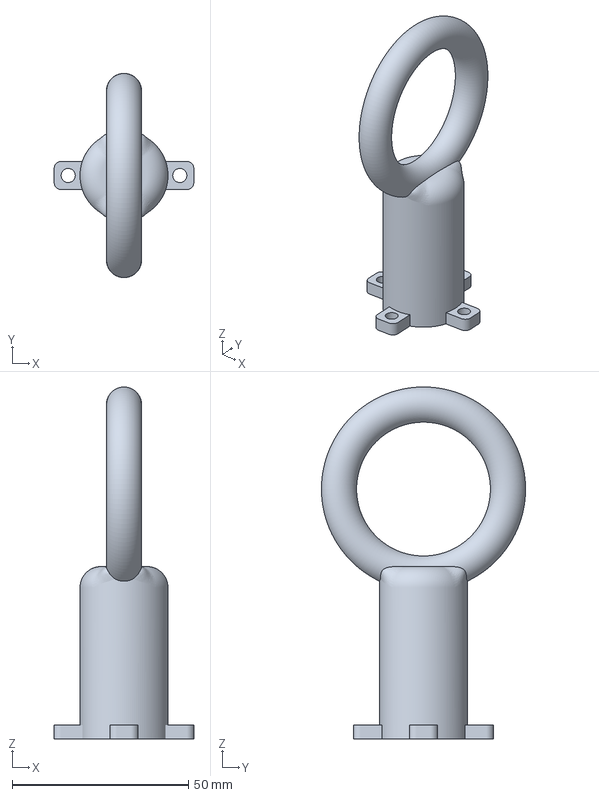
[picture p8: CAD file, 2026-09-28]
Case/string_pass1.3mf
39.7 x 58.0 x 100.0 mm

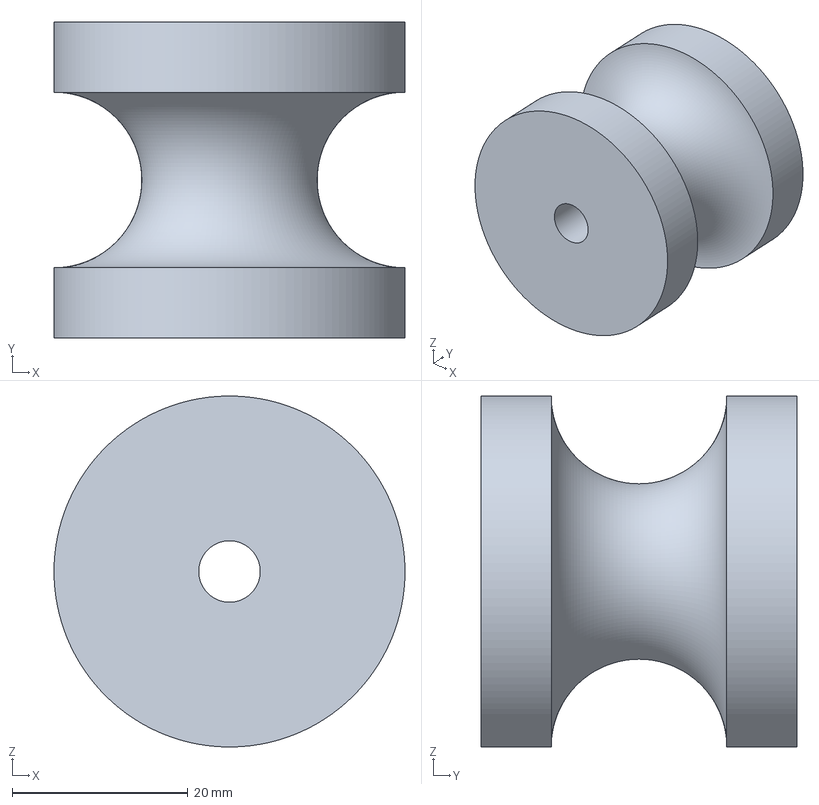
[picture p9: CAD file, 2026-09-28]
Case/Bottom_roll.3mf
40.0 x 36.0 x 40.0 mm

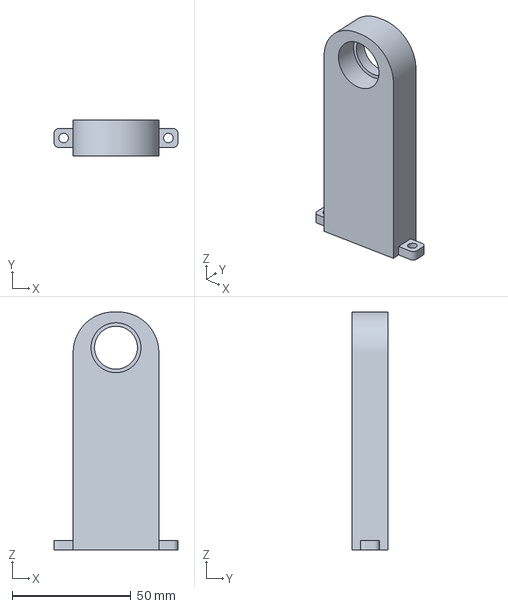
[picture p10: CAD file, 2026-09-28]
Case/bottom_roll_placement.3mf
52.0 x 15.0 x 100.0 mm

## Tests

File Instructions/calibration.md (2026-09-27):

# Calibrating the machine

Calibrate before first use, whenever you switch to a different type of wire, and whenever the lengths the machine measures start to drift.

## Prepare

1. Take a piece of the **same wire** you are going to wind.
2. The longer the piece, the more accurate the result. Use **at least 2 m**, and 5–10 m if you can.
3. Straighten it without stretching it, measure it carefully in millimetres, and cut it to that exact length. Write the number down.

## Calibrate

1. **Start:** press the **measuring encoder** button.
2. **Length:** turn the **user knob** until the display shows the length of your piece in mm.
   - Turn slowly for 1 mm steps, and faster for bigger steps.
   - Click the user knob.
3. **Mode:** turn the knob to choose `Auto` (the motor pulls the wire) or `HAnd` (you pull it yourself), then click.
4. **Pull the wire through:**
   - **`Auto`:** the display shows `tIE End`.
     1. Hold the front end of the wire at the measuring roll.
     2. Push the wire through the roll and tie it to the motor.
     3. Click. The motor starts.
     4. Wait until the **whole piece, including its tail, has passed the roll**, then click to stop the motor.
   - **`HAnd`:** the display shows `0`.
     1. Hold the front end of the wire at the measuring roll.
     2. Pull the whole piece through at a steady pace, keeping it taut, until the **tail has passed the roll**.
     3. Click.
5. **Finish:** the display shows a number, and the new calibration is saved automatically.
   - In `Auto` mode, wait until the motor has fully stopped.
   - Click to finish.

## Check

1. Run the calibration again with the same piece of wire.
2. On step 4, the number on the display should end close to the piece's real length.
3. If it's off by more than you can accept, calibrate once more, pulling more steadily.

## If something goes wrong

- **`Err` at the end:** the roll didn't count anything. Check that the wire actually presses on the roll, then start again.
- **`FLSH Err` at the end:** the calibration couldn't be saved. It works until you switch the machine off. Calibrate again after the next power-on.
- **The wire slipped, or you made a mistake:** just finish the steps and calibrate again. Only the last calibration counts.

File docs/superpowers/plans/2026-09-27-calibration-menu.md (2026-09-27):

# Calibration Menu Implementation Plan

> **For agentic workers:** REQUIRED SUB-SKILL: Use superpowers:subagent-driven-development (recommended) or superpowers:executing-plans to implement this plan task-by-task. Steps use checkbox (`- [ ]`) syntax for tracking.

**Goal:** Replace the placeholder Calibration menu with the real five-page flow. The flow measures how many measuring-roll ticks a known length of wire produces, computes the new mm/tick ratio, and saves it as JSON in flash, so the ratio survives a power cycle.

**Architecture:** The pure logic is hardware-free and host-tested, like the existing menu core:
- a "skip this tab" hook in `Menu`, used to skip page 2.5 in hand mode;
- `KnobAccel`, which turns knob turns into a speed-dependent step;
- the settings JSON codec;
- the calibration maths.

Only two new files touch the SDK. `settings_store.cpp` reads and writes the JSON text in the last 4 KB flash sector. `calibration_menu.cpp` holds the five `MenuTab` pages, which draw on the display and drive the motor and the measuring encoder. `Code/settings.json` holds the defaults and is compiled into the firmware through a header that CMake generates.

**Tech Stack:** C++17, Raspberry Pi Pico SDK 2.3.1 (RP2350B, Ninja), `hardware_flash` + `pico_flash` (`flash_safe_execute`), host tests with the system `g++` and the existing `CHECK` macro.

## Global Constraints

- The pages, in order (from the user's spec):
  1. **Length:** the user sets how much wire (mm) will go through, with the user knob. Clockwise adds, counter-clockwise subtracts.
  2. **Mode:** shows "by motor" first. One knob detent switches to "by hand", and the next one switches back.
  - 2.5. **Attach (motor mode only):** tick counting starts, the motor does **not** run yet, and the user ties the rope end to the motor. In hand mode this page is **not shown**.
  3. **Move:** the rope goes through the machine. In motor mode the motor runs. The display shows the length computed with the **old** ratio. If that number needs more than 8 digits, it is no longer shown (`--------`). Ticks are counted all the time.
  4. **Result:** shows how many ticks were counted. On entering this page, the new mm/tick is computed and saved.
- User decisions (asked 2026-09-27):
  - The settings are stored as **JSON text in the last flash sector**. `Code/settings.json` provides the compiled-in defaults.
  - Page 3 ends with a **user-knob click**, which also stops the motor.
  - The page 1 step depends on **turning speed**: 1 / 10 / 100 mm per detent.
  - The default ratio is **`"mm_per_tick": 1.0`**, so before the first calibration the display shows raw ticks.
- Page 1 starts at **1000 mm**. The range is **1 … 99 999 999 mm** (8 display digits).
- Display texts (the 7-segment font has no `M` and no `X`): mode "by motor" = `Auto`, "by hand" = `HAnd`, attach page = `tIE End`, value too large = `--------`, invalid result = `Err`, flash write failed = `FLSH Err`.
- The mm/tick ratio is `length_mm / |ticks|`. The sign is ignored, because the roll may turn either way depending on how the wire is threaded. With 0 ticks there is no result and nothing is saved.
- The hardware-free files (`menu.*`, `knob_accel.*`, `settings.*`, `calibration.*`) must not include Pico SDK headers. They may use `<stdint.h>`, `<stddef.h>`, `<stdio.h>`, `<stdlib.h>`, `<string.h>` and `<math.h>` (C++ `<c…>` forms in `.cpp`).
- No heap in the firmware: no `new`, `std::function`, `std::vector` or `std::string`.
- Code style: `snake_case_` members, `camelCase()` methods, `kConstant` constants, 4-space indent, `#pragma once`, and the comment density of the existing files.
- Every new firmware `.cpp` goes into `add_executable(Code ...)`. Every new hardware-free `.cpp` also goes into `SOURCES` in `Code/tests/run_tests.sh`. Do not edit the `DO NOT EDIT` block in `Code/CMakeLists.txt`.
- The working tree has unrelated changes (Case/, PCB/). **Commit only the paths listed in each task** (`git commit -- <paths>`). Never use `git add -A` or `git commit -a`.

## File Structure

All paths are relative to the repository root.

| File | Responsibility |
|---|---|
| `Code/menu.{h,cpp}` (modify) | `MenuTab::isSkipped()`; `Menu` skips tabs that return true |
| `Code/knob_accel.{h,cpp}` (create) | `KnobAccel`: detents → value step, ×1 / ×10 / ×100 by the gap between turns |
| `Code/settings.{h,cpp}` (create) | `Settings` struct, `parseSettingsJson()`, `formatSettingsJson()` |
| `Code/settings.json` (create) | Default settings, compiled into the firmware |
| `Code/calibration.{h,cpp}` (create) | Length limits, `adjustLength()`, `computeMmPerTick()`, `ticksToMm()`, `fitsDisplay()` |
| `Code/settings_store.{h,cpp}` (create) | `loadSettings()` / `saveSettings()`: the last flash sector, with fallback to the compiled-in defaults |
| `Code/calibration_menu.{h,cpp}` (create) | `CalibrationContext`, the five page tabs, `CalibrationMenu` |
| `Code/tests/fake_tab.h` (modify) | `skipped` flag |
| `Code/tests/test_menu.cpp` (modify) | Skip tests |
| `Code/tests/test_knob_accel.cpp`, `test_settings.cpp`, `test_calibration.cpp` (create) | One suite per unit |
| `Code/tests/test_main.cpp`, `Code/tests/run_tests.sh` (modify) | Register the new suites and sources |
| `Code/CMakeLists.txt` (modify) | Sources, the `settings_default.h` generation, flash libraries |
| `Code/Code.cpp` (modify) | Load the settings at boot and register the real Calibration menu |
| `Code/CLAUDE.md` (modify) | Document the settings, the calibration flow, and the skip hook |

Commands used throughout (run from the repo root):
- Host tests: `Code/tests/run_tests.sh`
- Firmware build: `~/.pico-sdk/ninja/v1.13.2/ninja -C Code/build`

---

### Task 1: Skippable tabs in `Menu`

**Files:**
- Modify: `Code/menu.h`, `Code/menu.cpp`
- Modify: `Code/tests/fake_tab.h`, `Code/tests/test_menu.cpp`

**Interfaces:**
- Consumes: the existing `MenuTab`, `Menu`, `TabAction`.
- Produces: `virtual bool MenuTab::isSkipped() const` (default `false`). `Menu::open()` enters the first non-skipped tab. `TabAction::Next` goes to the next non-skipped tab, or closes the menu if there is none. Skipping is decided **at the moment of the transition**, so a tab can depend on a choice made on an earlier page.

- [ ] **Step 1: Add the `skipped` flag to `FakeTab`**

In `Code/tests/fake_tab.h`, add a member and an override to `FakeTab`:

```cpp
    bool skipped = false;  // isSkipped() result
```

(next to `Menu *close_on_exit = nullptr;`) and

```cpp
    bool isSkipped() const override { return skipped; }
```

(next to `void onEnter() override`).

- [ ] **Step 2: Write the failing tests**

In `Code/tests/test_menu.cpp`, add these functions inside the anonymous namespace, before its closing `}` (`HookMenu` is already defined at the top of that namespace):

```cpp
void testSkippedTabIsPassedOver() {
    FakeTab a, b, c;
    b.skipped = true;
    Menu m;
    m.addTab(a);
    m.addTab(b);
    m.addTab(c);
    m.open();
    m.click();
    CHECK(m.currentTab() == 2);
    CHECK(b.enters == 0);
    CHECK(b.exits == 0);
    CHECK(c.enters == 1);
}

void testSkipIsDecidedAtTransition() {
    FakeTab a, b, c;
    Menu m;
    m.addTab(a);
    m.addTab(b);
    m.addTab(c);
    m.open();
    b.skipped = true;  // e.g. a choice made on tab a
    m.click();
    CHECK(m.currentTab() == 2);
    CHECK(b.enters == 0);
}

void testSkippedLastTabCloses() {
    FakeTab a, b;
    b.skipped = true;
    HookMenu m;
    m.addTab(a);
    m.addTab(b);
    m.open();
    m.click();
    CHECK(!m.isOpen());
    CHECK(a.exits == 1);
    CHECK(b.enters == 0);
    CHECK(m.closes == 1);
}

void testSkippedFirstTab() {
    FakeTab a, b;
    a.skipped = true;
    Menu m;
    m.addTab(a);
    m.addTab(b);
    m.open();
    CHECK(m.currentTab() == 1);
    CHECK(a.enters == 0);
    CHECK(b.enters == 1);
}

void testAllTabsSkippedClosesImmediately() {
    FakeTab a;
    a.skipped = true;
    HookMenu m;
    m.addTab(a);
    m.open();
    CHECK(!m.isOpen());
    CHECK(a.enters == 0);
    CHECK(m.opens == 1);
    CHECK(m.closes == 1);
}
```

Then call them from `runMenuTests()` (append after the existing calls):

```cpp
    testSkippedTabIsPassedOver();
    testSkipIsDecidedAtTransition();
    testSkippedLastTabCloses();
    testSkippedFirstTab();
    testAllTabsSkippedClosesImmediately();
```

- [ ] **Step 3: Run the tests and check that they fail**

Run: `Code/tests/run_tests.sh`
Expected: a compile error, `'bool FakeTab::isSkipped() const' marked 'override', but does not override`.

- [ ] **Step 4: Add the hook to `MenuTab`**

In `Code/menu.h`, inside `class MenuTab`, after `onExit()`:

```cpp
    // Return true to leave this tab out of the sequence. Asked every time
    // the menu moves to it, so it can depend on an earlier tab's choice.
    virtual bool isSkipped() const { return false; }
```

In `class Menu`, `private:` section, after `void finishClose();`:

```cpp
    // Index of the first tab at or after `index` that is not skipped, -1 if none.
    int firstShownFrom(int index) const;
```

- [ ] **Step 5: Implement skipping in `Menu`**

In `Code/menu.cpp`, replace `Menu::open()`:

```cpp
void Menu::open() {
    if (isOpen()) return;
    onOpen();
    int first = firstShownFrom(0);
    if (first < 0) {  // nothing to show: open and close right away
        onClose();
        return;
    }
    current_ = first;
    tabs_[current_]->onEnter();
}
```

Add after `Menu::finishClose()`:

```cpp
int Menu::firstShownFrom(int index) const {
    for (int i = index; i < tab_count_; i++) {
        if (!tabs_[i]->isSkipped()) return i;
    }
    return -1;
}
```

Replace the `case TabAction::Next:` block in `Menu::apply()`:

```cpp
        case TabAction::Next: {
            leaveCurrent();
            // Asked after onExit(), so the leaving tab's choice is already stored
            int next = firstShownFrom(current_ + 1);
            if (close_requested_ || next < 0) {  // past the last shown tab, or closed from onExit()
                finishClose();
                break;
            }
            current_ = next;
            tabs_[current_]->onEnter();
            break;
        }
```

- [ ] **Step 6: Run the tests and check that they pass**

Run: `Code/tests/run_tests.sh`
Expected: `All tests passed`. The existing re-entrancy tests (`testCloseFromOnExitDuringNext`, `testClickOnLastTabCloses`) must still pass.

- [ ] **Step 7: Commit**

```bash
git add Code/menu.h Code/menu.cpp Code/tests/fake_tab.h Code/tests/test_menu.cpp
git commit -m "feat(firmware): let menu tabs be skipped based on earlier choices

Co-Authored-By: Claude Opus 5.5 <noreply@anthropic.com>" -- Code/menu.h Code/menu.cpp Code/tests/fake_tab.h Code/tests/test_menu.cpp
```

---

### Task 2: `KnobAccel` (speed-dependent step)

**Files:**
- Create: `Code/knob_accel.h`, `Code/knob_accel.cpp`, `Code/tests/test_knob_accel.cpp`
- Modify: `Code/tests/test_main.cpp`, `Code/tests/run_tests.sh`, `Code/CMakeLists.txt`

**Interfaces:**
- Consumes: none.
- Produces: `class KnobAccel { static constexpr uint32_t kFastGapMs = 40; static constexpr uint32_t kMediumGapMs = 100; int32_t scale(int32_t detents, uint32_t now_ms); void reset(); }`. `scale()` returns `detents × factor`. The factor is 100 if the previous turn was ≤ `kFastGapMs` ago, 10 if it was ≤ `kMediumGapMs` ago, and 1 otherwise (and always 1 for the first turn after `reset()`). `detents == 0` returns 0 and does not count as a turn.

- [ ] **Step 1: Write the failing test**

`Code/tests/test_knob_accel.cpp`:

```cpp
#include "check.h"
#include "knob_accel.h"

namespace {

void testFirstTurnIsFine() {
    KnobAccel accel;
    CHECK(accel.scale(1, 1000) == 1);
    CHECK(accel.scale(-1, 5000) == -1);  // long pause: fine again
}

void testMediumAndFastTurns() {
    KnobAccel accel;
    accel.scale(1, 1000);
    CHECK(accel.scale(1, 1000 + KnobAccel::kMediumGapMs) == 10);
    CHECK(accel.scale(-2, 1100 + KnobAccel::kFastGapMs) == -200);
    CHECK(accel.scale(1, 1140 + KnobAccel::kMediumGapMs + 1) == 1);
}

void testZeroIsNotATurn() {
    KnobAccel accel;
    accel.scale(1, 1000);
    CHECK(accel.scale(0, 1010) == 0);
    CHECK(accel.scale(1, 1000 + KnobAccel::kMediumGapMs) == 10);  // gap still from t=1000
}

void testResetForgetsLastTurn() {
    KnobAccel accel;
    accel.scale(1, 1000);
    accel.reset();
    CHECK(accel.scale(1, 1010) == 1);
}

void testTimeWraparound() {
    KnobAccel accel;
    accel.scale(1, 0xFFFFFFF0u);
    CHECK(accel.scale(1, 0x00000010u) == 100);  // 32 ms across the wrap
}

}  // namespace

void runKnobAccelTests() {
    testFirstTurnIsFine();
    testMediumAndFastTurns();
    testZeroIsNotATurn();
    testResetForgetsLastTurn();
    testTimeWraparound();
}
```

In `Code/tests/test_main.cpp`, declare `void runKnobAccelTests();` next to the other declarations and call `runKnobAccelTests();` after `runMenuManagerTests();`.

In `Code/tests/run_tests.sh`, change `SOURCES` to:

```sh
SOURCES="../click_detector.cpp ../menu.cpp ../menu_manager.cpp ../knob_accel.cpp"
```

- [ ] **Step 2: Run the test and check that it fails**

Run: `Code/tests/run_tests.sh`
Expected: a compile error, `knob_accel.h: No such file or directory`.

- [ ] **Step 3: Implement**

`Code/knob_accel.h`:

```cpp
#pragma once

#include <stdint.h>

// Speed-dependent step for editing a number with the user knob: slow turns
// change it by 1 per detent, faster turns by 10 or 100, so both fine
// adjustment and big jumps are quick. Pure logic; the caller passes the time.
class KnobAccel {
public:
    static constexpr uint32_t kFastGapMs = 40;     // turns this close: x100
    static constexpr uint32_t kMediumGapMs = 100;  // turns this close: x10

    // Returns detents scaled by the factor for the gap since the previous
    // turn. detents == 0 returns 0 and is not counted as a turn. now_ms may wrap around.
    int32_t scale(int32_t detents, uint32_t now_ms);

    // Forgets the previous turn, so the next one is x1.
    void reset();

private:
    bool has_last_ = false;
    uint32_t last_ms_ = 0;
};
```

`Code/knob_accel.cpp`:

```cpp
#include "knob_accel.h"

int32_t KnobAccel::scale(int32_t detents, uint32_t now_ms) {
    if (detents == 0) return 0;
    int32_t factor = 1;
    if (has_last_) {
        uint32_t gap = now_ms - last_ms_;  // unsigned: correct across the wrap
        if (gap <= kFastGapMs) {
            factor = 100;
        } else if (gap <= kMediumGapMs) {
            factor = 10;
        }
    }
    has_last_ = true;
    last_ms_ = now_ms;
    return detents * factor;
}

void KnobAccel::reset() {
    has_last_ = false;
}
```

In `Code/CMakeLists.txt`, extend `add_executable`:

```cmake
add_executable(Code Code.cpp max7219.cpp rotary_encoder.cpp motor.cpp
        click_detector.cpp menu.cpp menu_manager.cpp knob_accel.cpp)
```

- [ ] **Step 4: Run the tests and check that they pass**

Run: `Code/tests/run_tests.sh`
Expected: `All tests passed`.

- [ ] **Step 5: Commit**

```bash
git add Code/knob_accel.h Code/knob_accel.cpp Code/tests/test_knob_accel.cpp
git commit -m "feat(firmware): add KnobAccel for speed-dependent knob steps

Co-Authored-By: Claude Opus 5.5 <noreply@anthropic.com>" -- Code/knob_accel.h Code/knob_accel.cpp Code/tests/test_knob_accel.cpp Code/tests/test_main.cpp Code/tests/run_tests.sh Code/CMakeLists.txt
```

---

### Task 3: Settings JSON codec + `settings.json`

**Files:**
- Create: `Code/settings.h`, `Code/settings.cpp`, `Code/settings.json`, `Code/tests/test_settings.cpp`
- Modify: `Code/tests/test_main.cpp`, `Code/tests/run_tests.sh`, `Code/CMakeLists.txt`

**Interfaces:**
- Consumes: none.
- Produces:
  - `struct Settings { double mm_per_tick = 1.0; };`
  - `bool parseSettingsJson(const char *text, Settings &out);` takes NUL-terminated text. It reads `"mm_per_tick"`, which must be a finite number > 0. It returns false and leaves `out` unchanged if the key is missing or invalid.
  - `int formatSettingsJson(const Settings &settings, char *buf, size_t size);` writes NUL-terminated JSON. It returns the length without the NUL, or -1 if `buf` is too small.
  - `Code/settings.json` is the default-settings file. Task 5 compiles it into the firmware.

- [ ] **Step 1: Create the defaults file**

`Code/settings.json`:

```json
{
    "mm_per_tick": 1.0
}
```

- [ ] **Step 2: Write the failing test**

`Code/tests/test_settings.cpp`:

```cpp
#include <cmath>
#include <cstdio>
#include <cstring>

#include "check.h"
#include "settings.h"

namespace {

void testParsesValue() {
    Settings s;
    CHECK(parseSettingsJson("{\"mm_per_tick\": 0.125}", s));
    CHECK(s.mm_per_tick == 0.125);
}

void testParsesWithWhitespace() {
    Settings s;
    CHECK(parseSettingsJson("{\n    \"mm_per_tick\" :\t2.5\n}\n", s));
    CHECK(s.mm_per_tick == 2.5);
}

void testRejectsBadValues() {
    const char *bad[] = {
        "",
        "{}",
        "{\"mm_per_tick\": }",
        "{\"mm_per_tick\": \"abc\"}",
        "{\"mm_per_tick\" 1.0}",
        "{\"mm_per_tick\": 0}",
        "{\"mm_per_tick\": -1.5}",
        "{\"mm_per_tick\": nan}",
        "{\"mm_per_tick\": inf}",
    };
    for (const char *text : bad) {
        Settings s;
        s.mm_per_tick = 3.0;
        CHECK(!parseSettingsJson(text, s));
        CHECK(s.mm_per_tick == 3.0);  // unchanged on failure
    }
    Settings s;
    CHECK(!parseSettingsJson(nullptr, s));
}

void testFormatRoundTrip() {
    Settings s;
    s.mm_per_tick = 0.0123456789;
    char buf[64];
    int n = formatSettingsJson(s, buf, sizeof(buf));
    CHECK(n > 0);
    CHECK((size_t)n == std::strlen(buf));
    Settings back;
    CHECK(parseSettingsJson(buf, back));
    CHECK(std::fabs(back.mm_per_tick - s.mm_per_tick) < s.mm_per_tick * 1e-8);
}

void testFormatBufferTooSmall() {
    Settings s;
    char buf[8];
    CHECK(formatSettingsJson(s, buf, sizeof(buf)) == -1);
}

void testRepoDefaultsFileIsValid() {
    // run_tests.sh runs from Code/tests
    std::FILE *f = std::fopen("../settings.json", "r");
    CHECK(f != nullptr);
    if (f == nullptr) return;
    char buf[512] = {};
    CHECK(std::fread(buf, 1, sizeof(buf) - 1, f) > 0);
    std::fclose(f);
    Settings s;
    s.mm_per_tick = 99.0;
    CHECK(parseSettingsJson(buf, s));
    CHECK(s.mm_per_tick == 1.0);
}

}  // namespace

void runSettingsTests() {
    testParsesValue();
    testParsesWithWhitespace();
    testRejectsBadValues();
    testFormatRoundTrip();
    testFormatBufferTooSmall();
    testRepoDefaultsFileIsValid();
}
```

In `Code/tests/test_main.cpp`, declare `void runSettingsTests();` and call it after `runKnobAccelTests();`.

In `Code/tests/run_tests.sh`:

```sh
SOURCES="../click_detector.cpp ../menu.cpp ../menu_manager.cpp ../knob_accel.cpp ../settings.cpp"
```

- [ ] **Step 3: Run the test and check that it fails**

Run: `Code/tests/run_tests.sh`
Expected: a compile error, `settings.h: No such file or directory`.

- [ ] **Step 4: Implement**

`Code/settings.h`:

```cpp
#pragma once

#include <stddef.h>

// Values that must survive a power cycle. Stored as JSON text (see
// settings_store.h); the defaults come from settings.json.
struct Settings {
    double mm_per_tick = 1.0;  // wire length per measuring-roll quadrature step
};

// Reads the settings from NUL-terminated JSON text. Only the keys it knows
// are read; returns false and leaves `out` unchanged if "mm_per_tick" is
// missing or not a finite number > 0.
bool parseSettingsJson(const char *text, Settings &out);

// Writes the settings as NUL-terminated JSON. Returns the length (without
// the NUL), or -1 if `size` is too small.
int formatSettingsJson(const Settings &settings, char *buf, size_t size);
```

`Code/settings.cpp`:

```cpp
#include "settings.h"

#include <cmath>
#include <cstdio>
#include <cstdlib>
#include <cstring>

namespace {

constexpr char kMmPerTickKey[] = "\"mm_per_tick\"";

}  // namespace

// A minimal reader for our own flat file, not a general JSON parser.
bool parseSettingsJson(const char *text, Settings &out) {
    if (text == nullptr) return false;
    const char *key = std::strstr(text, kMmPerTickKey);
    if (key == nullptr) return false;

    const char *p = key + sizeof(kMmPerTickKey) - 1;
    while (*p == ' ' || *p == '\t' || *p == '\r' || *p == '\n') p++;
    if (*p != ':') return false;
    p++;

    char *end = nullptr;
    double value = std::strtod(p, &end);  // skips leading whitespace itself
    if (end == p || !std::isfinite(value) || value <= 0.0) return false;

    out.mm_per_tick = value;
    return true;
}

int formatSettingsJson(const Settings &settings, char *buf, size_t size) {
    // 9 significant digits keep the ratio accurate to far below one tick per km
    int n = std::snprintf(buf, size, "{\"mm_per_tick\": %.9g}\n", settings.mm_per_tick);
    if (n < 0 || (size_t)n >= size) return -1;
    return n;
}
```

In `Code/CMakeLists.txt`, append `settings.cpp` to `add_executable(Code ...)` (after `knob_accel.cpp`).

- [ ] **Step 5: Run the tests and check that they pass**

Run: `Code/tests/run_tests.sh`
Expected: `All tests passed`.

- [ ] **Step 6: Commit**

```bash
git add Code/settings.h Code/settings.cpp Code/settings.json Code/tests/test_settings.cpp
git commit -m "feat(firmware): add settings JSON codec and default settings.json

Co-Authored-By: Claude Opus 5.5 <noreply@anthropic.com>" -- Code/settings.h Code/settings.cpp Code/settings.json Code/tests/test_settings.cpp Code/tests/test_main.cpp Code/tests/run_tests.sh Code/CMakeLists.txt
```

---
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

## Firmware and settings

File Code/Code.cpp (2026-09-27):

#include <stdio.h>
#include "pico/stdlib.h"
#include "max7219.h"
#include "rotary_encoder.h"
#include "motor.h"
#include "click_detector.h"
#include "menu.h"
#include "menu_manager.h"
#include "settings_store.h"
#include "calibration_menu.h"
#include "working_menu.h"

// MAX7219 wiring (SPI0)
constexpr uint DISPLAY_SCK_PIN  = 18;  // CLK
constexpr uint DISPLAY_MOSI_PIN = 19;  // DIN
constexpr uint DISPLAY_CS_PIN   = 17;  // CS / LOAD

// KY-040 encoders (powered from 3.3 V)
constexpr uint MEASURE_ENC_CLK_PIN = 2;  // encoder geared to the measuring roll
constexpr uint MEASURE_ENC_DT_PIN  = 3;
constexpr uint MEASURE_ENC_SW_PIN  = 4;
constexpr uint USER_ENC_CLK_PIN    = 6;  // encoder for setting length / calibration
constexpr uint USER_ENC_DT_PIN     = 7;
constexpr uint USER_ENC_SW_PIN     = 8;

// Motor driver input (BC547 -> IRF3205, inverting: high = stopped)
constexpr uint MOTOR_PWM_PIN = 10;

constexpr uint32_t LOOP_PERIOD_MS = 5;
constexpr uint32_t DISPLAY_REFRESH_MS = 250;  // heals a display corrupted by a noisy SPI frame

Max7219 display(spi0, DISPLAY_SCK_PIN, DISPLAY_MOSI_PIN, DISPLAY_CS_PIN);
RotaryEncoder measureEncoder(MEASURE_ENC_CLK_PIN, MEASURE_ENC_DT_PIN, MEASURE_ENC_SW_PIN);
RotaryEncoder userEncoder(USER_ENC_CLK_PIN, USER_ENC_DT_PIN, USER_ENC_SW_PIN);
Motor motor(MOTOR_PWM_PIN);

namespace {

// Idle screen (after power-up and whenever a menu closes): every segment
// and dot lit, which also shows at a glance if a segment is dead.
void showIdleScreen() {
    for (int pos = 0; pos < Max7219::kDigits; pos++) display.setSegments(pos, 0xFF);
}

Settings settings;  // loaded from flash in main(); the calibration menu updates it

WorkingContext working{display, motor, measureEncoder, settings};
WorkingMenu workingMenu(working);

CalibrationContext calibration{display, motor, measureEncoder, settings, saveSettings};
CalibrationMenu calibrationMenu(calibration);

MenuManager menus(showIdleScreen);

}  // namespace

int main()
{
    motor.init();  // first: until then the driver sees a low pin = full speed
    stdio_init_all();
    settings = loadSettings();  // settings.json defaults, overridden by the last calibration
    display.init(15);
    measureEncoder.init();
    userEncoder.init();

    // Working menu: user knob click. Calibration: measuring encoder click.
    // Tabs of both menus are advanced by a short click on the user knob.
    menus.addMenu(MenuTrigger::UserClick, workingMenu);
    menus.addMenu(MenuTrigger::MeasureClick, calibrationMenu);
    menus.begin();  // idle: all segments lit, no menu until a click

    ClickDetector userClicks;
    ClickDetector measureClicks;
    uint32_t last_display_refresh = 0;

    while (true) {
        uint32_t now = to_ms_since_boot(get_absolute_time());

        MenuInput input;
        input.user_turn = userEncoder.readDelta();  // read every pass so idle turns are dropped
        ClickEvent user_click = userClicks.update(userEncoder.isPressed(), now);
        input.user_click = user_click == ClickEvent::Short;
        input.user_long_click = user_click == ClickEvent::Long;
        input.measure_click = measureClicks.update(measureEncoder.isPressed(), now) == ClickEvent::Short;
        // measureEncoder.readDelta() is deliberately not drained: the measuring roll uses getCount(),
        // so a later readDelta() would return everything since boot.
        menus.process(input, now);

        if (now - last_display_refresh >= DISPLAY_REFRESH_MS) {
            display.refresh();
            last_display_refresh = now;
        }

        sleep_ms(LOOP_PERIOD_MS);
    }
}

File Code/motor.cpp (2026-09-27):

#include "motor.h"

#include "pico/stdlib.h"
#include "hardware/clocks.h"
#include "hardware/gpio.h"
#include "hardware/pwm.h"
#include "hardware/sync.h"

namespace {

constexpr int kUpdateMs = 5;  // ramp step period

// Smoothstep: zero slope at both ends, so the motor starts and settles
// without a jerk.
float sCurve(float t) {
    return t * t * (3.0f - 2.0f * t);
}

}  // namespace

Motor::Motor(uint pwm_pin, uint32_t ramp_ms, uint32_t pwm_hz)
    : pwm_pin_(pwm_pin),
      slice_(pwm_gpio_to_slice_num(pwm_pin)),
      channel_(pwm_gpio_to_channel(pwm_pin)),
      ramp_us_(ramp_ms * 1000),
      pwm_hz_(pwm_hz > 0 ? pwm_hz : kDefaultPwmHz) {}

void Motor::init() {
    // Drive the pin high (motor off) before handing it to the PWM, so the
    // motor does not twitch while the slice is being configured.
    gpio_init(pwm_pin_);
    gpio_set_dir(pwm_pin_, GPIO_OUT);
    gpio_put(pwm_pin_, 1);

    // Pick the smallest integer divider that keeps TOP + 1 (the full-speed
    // level) within 16 bits, for the finest duty resolution.
    uint32_t sys_hz = clock_get_hz(clk_sys);
    uint32_t div = (sys_hz / pwm_hz_ + 65534) / 65535;
    if (div < 1) div = 1;
    if (div > 255) div = 255;
    top_ = (uint16_t)(sys_hz / (div * pwm_hz_) - 1);

    pwm_config config = pwm_get_default_config();
    pwm_config_set_clkdiv_int(&config, div);
    pwm_config_set_wrap(&config, top_);
    // Inverted output: level 0 = pin always high = motor stopped
    pwm_config_set_output_polarity(&config, channel_ == PWM_CHAN_A, channel_ == PWM_CHAN_B);
    pwm_init(slice_, &config, false);
    pwm_set_chan_level(slice_, channel_, 0);
    pwm_set_enabled(slice_, true);
    gpio_set_function(pwm_pin_, GPIO_FUNC_PWM);

    // Negative delay = fixed period, measured from the previous start
    add_repeating_timer_ms(-kUpdateMs, timerCallback, this, &timer_);
}

void Motor::start() {
    running_ = true;
    rampTo(max_percent_ / 100.0f, ramp_us_);
}

void Motor::stop() {
    running_ = false;
    rampTo(0.0f, ramp_us_);
}

void Motor::setMaxSpeed(uint8_t percent) {
    max_percent_ = percent > 100 ? 100 : percent;
    if (running_) rampTo(max_percent_ / 100.0f, ramp_us_);
}

uint8_t Motor::getMaxSpeed() const {
    return max_percent_;
}

float Motor::getSpeed() const {
    return speed_;
}

bool Motor::isRunning() const {
    return running_ || ramping_ || speed_ > 0.0f;
}

void Motor::setSpeed(float speed, uint32_t ramp_ms) {
    if (speed < 0.0f) speed = 0.0f;
    if (speed > 1.0f) speed = 1.0f;
    running_ = speed > 0.0f;
    rampTo(speed, (uint64_t)ramp_ms * 1000);
}

bool Motor::isRamping() const {
    return ramping_;
}

// Starts a new ramp from wherever the motor is now, so calling stop() in the
// middle of a start (or vice versa) does not cause a speed jump.
void Motor::rampTo(float target, uint64_t ramp_us) {
    uint32_t irq_state = save_and_disable_interrupts();
    ramp_from_ = speed_;
    ramp_to_ = target;
    ramp_start_us_ = time_us_64();
    ramp_len_us_ = ramp_us;
    ramping_ = true;
    restore_interrupts(irq_state);
}

void Motor::applySpeed(float speed) {
    // With the inverted polarity the pin is low (motor on) for `level` counts
    // out of TOP + 1, so level = TOP + 1 is a constant low = full speed.
    uint32_t level = (uint32_t)(speed * (top_ + 1u) + 0.5f);
    pwm_set_chan_level(slice_, channel_, (uint16_t)(level > top_ + 1u ? top_ + 1u : level));
}

void Motor::update() {
    if (!ramping_) return;

    uint64_t elapsed = time_us_64() - ramp_start_us_;
    float speed;
    if (ramp_len_us_ == 0 || elapsed >= ramp_len_us_) {
        speed = ramp_to_;
        ramping_ = false;
    } else {
        float t = (float)elapsed / (float)ramp_len_us_;
        speed = ramp_from_ + (ramp_to_ - ramp_from_) * sCurve(t);
    }
    speed_ = speed;
    applySpeed(speed);
}

bool Motor::timerCallback(repeating_timer_t *t) {
    static_cast<Motor *>(t->user_data)->update();
    return true;  // keep repeating
}

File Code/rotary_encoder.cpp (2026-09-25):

#include "rotary_encoder.h"

#include "pico/stdlib.h"
#include "hardware/gpio.h"
#include "hardware/sync.h"

namespace {

constexpr uint32_t kEdges = GPIO_IRQ_EDGE_RISE | GPIO_IRQ_EDGE_FALL;
constexpr int kButtonPollMs = 1;
constexpr uint8_t kButtonDebounceMs = 10;  // level must be stable this long

// Quadrature decoding table, indexed by (previous AB << 2) | current AB.
// +1 / -1 for a valid step, 0 for no change or an invalid jump (both pins
// changed, e.g. a missed edge during contact bounce). Bounce on one contact
// produces +1/-1 pairs that cancel out.
const int8_t kQuadratureTable[16] = {
     0, -1, +1,  0,
    +1,  0,  0, -1,
    -1,  0,  0, +1,
     0, +1, -1,  0,
};

RotaryEncoder *g_encoders[RotaryEncoder::kMaxEncoders] = {};
repeating_timer_t g_button_timer;
bool g_button_timer_started = false;

}  // namespace

// The raw GPIO IRQ API takes a plain function without context, so each slot
// gets its own handler that forwards to the registered encoder.
template <int Slot>
void RotaryEncoder::gpioIrqTrampoline() {
    g_encoders[Slot]->handleGpioIrq();
}

static_assert(RotaryEncoder::kMaxEncoders == 4, "update kTrampolines");

RotaryEncoder::RotaryEncoder(uint clk_pin, uint dt_pin, uint sw_pin,
                             int steps_per_detent, bool reversed)
    : clk_pin_(clk_pin), dt_pin_(dt_pin), sw_pin_(sw_pin),
      steps_per_detent_(steps_per_detent > 0 ? steps_per_detent : 1),
      reversed_(reversed) {}

bool RotaryEncoder::init() {
    static const irq_handler_t kTrampolines[kMaxEncoders] = {
        &RotaryEncoder::gpioIrqTrampoline<0>,
        &RotaryEncoder::gpioIrqTrampoline<1>,
        &RotaryEncoder::gpioIrqTrampoline<2>,
        &RotaryEncoder::gpioIrqTrampoline<3>,
    };

    int slot = 0;
    while (slot < kMaxEncoders && g_encoders[slot] != nullptr) slot++;
    if (slot == kMaxEncoders) return false;

    auto initInput = [](uint pin) {
        gpio_init(pin);
        gpio_set_dir(pin, GPIO_IN);
        gpio_pull_up(pin);
    };
    initInput(clk_pin_);
    initInput(dt_pin_);
    if (sw_pin_ != kNoPin) initInput(sw_pin_);
    sleep_us(10);  // let the pull-ups settle before taking the initial state

    last_ab_ = (gpio_get(clk_pin_) << 1) | gpio_get(dt_pin_);

    g_encoders[slot] = this;  // must be set before the IRQ can fire

    // Rotation: interrupt on every edge of both pins, on the calling core
    gpio_add_raw_irq_handler_masked64((1ull << clk_pin_) | (1ull << dt_pin_),
                                      kTrampolines[slot]);
    gpio_set_irq_enabled(clk_pin_, kEdges, true);
    gpio_set_irq_enabled(dt_pin_, kEdges, true);
    irq_set_enabled(IO_IRQ_BANK0, true);

    // Button: one shared timer polls every registered encoder
    if (!g_button_timer_started) {
        // Negative delay = fixed period, measured from the previous start
        add_repeating_timer_ms(-kButtonPollMs, buttonTimerCallback, nullptr, &g_button_timer);
        g_button_timer_started = true;
    }
    return true;
}

int32_t RotaryEncoder::getCount() const {
    return count_;
}

int32_t RotaryEncoder::getPosition() const {
    return count_ / steps_per_detent_;
}

void RotaryEncoder::reset(int32_t position) {
    uint32_t irq_state = save_and_disable_interrupts();
    count_ = position * steps_per_detent_;
    delta_base_ = count_;
    restore_interrupts(irq_state);
}

int32_t RotaryEncoder::readDelta() {
    // Report a detent only after a full detent of travel in either direction,
    // so a knob resting between clicks does not jitter.
    int32_t detents = (count_ - delta_base_) / steps_per_detent_;
    delta_base_ += detents * steps_per_detent_;
    return detents;
}

bool RotaryEncoder::isPressed() const {
    return button_pressed_;
}

bool RotaryEncoder::wasClicked() {
    uint32_t irq_state = save_and_disable_interrupts();
    bool clicked = clicked_;
    clicked_ = false;
    restore_interrupts(irq_state);
    return clicked;
}

void RotaryEncoder::handleGpioIrq() {
    bool clk_event = gpio_get_irq_event_mask(clk_pin_) & kEdges;
    bool dt_event = gpio_get_irq_event_mask(dt_pin_) & kEdges;
    if (!clk_event && !dt_event) return;  // IRQ was for another pin
    if (clk_event) gpio_acknowledge_irq(clk_pin_, kEdges);
    if (dt_event) gpio_acknowledge_irq(dt_pin_, kEdges);

    uint8_t ab = (gpio_get(clk_pin_) << 1) | gpio_get(dt_pin_);
    int8_t step = kQuadratureTable[(last_ab_ << 2) | ab];
    last_ab_ = ab;
    count_ = count_ + (reversed_ ? -step : step);
}

void RotaryEncoder::pollButton() {
    bool raw = !gpio_get(sw_pin_);  // active low
    if (raw != button_raw_) {
        button_raw_ = raw;
        button_same_ms_ = 0;
        return;
    }
    if (button_same_ms_ < kButtonDebounceMs) {
        button_same_ms_++;
        if (button_same_ms_ == kButtonDebounceMs && raw != button_stable_) {
            button_stable_ = raw;
            button_pressed_ = raw;
            if (raw) clicked_ = true;
        }
    }
}

bool RotaryEncoder::buttonTimerCallback(repeating_timer_t *) {
    for (RotaryEncoder *encoder : g_encoders) {
        if (encoder != nullptr && encoder->sw_pin_ != kNoPin) encoder->pollButton();
    }
    return true;  // keep repeating
}

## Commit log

2026-09-16 Top and bottom rolls
    [wire_counting_machine.FCStd]
2026-09-20 The case without electronics and schematic
    [PCB, Schematic and Components.kicad_pcb, PCB, Schematic and Components.kicad_sch, wire_counting_machine.FCStd]
2026-09-25 chore(firmware): add existing firmware (display, encoders, motor)
2026-09-25 feat(firmware): add MenuManager with exclusive menus and idle screen
    Constraint: calibration must never start while the working menu is open
    Rejected: opening a menu closes the other | lets a stray click abort a run
    Directive: triggers are ignored while any menu is open - keep it that way
    Confidence: high
    Scope-risk: narrow
2026-09-25 feat(firmware): run the main loop through the menu manager
    Boot shows all segments lit; the user knob opens the working menu and the
    measuring encoder opens calibration. Both menus hold placeholder label tabs
    until the real pages are written.
    Directive: LabelTab menus in Code.cpp are placeholders - replace, do not extend
    Confidence: medium
    Scope-risk: moderate
    Not-tested: behaviour with the motor running (motor test loop removed)
    [Code.cpp]
2026-09-25 docs(firmware): clarify encoder click API and menu usage notes
    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
2026-09-27 docs: add calibration menu implementation plan
2026-09-27 feat(firmware): add calibration maths (mm/tick ratio, length limits)
    Implement pure-math calibration module with adjustLength(), computeMmPerTick(),
    ticksToMm(), and fitsDisplay() functions. All hardware-free functions are
    host-tested via test_calibration.cpp, passing all test cases.
    Firmware builds successfully with ninja. No uncommitted changes to unrelated files.
2026-09-27 feat(firmware): add the calibration menu pages and save the mm/tick ratio
2026-09-27 docs(firmware): document settings storage and the calibration menu
2026-09-27 fix(firmware): save calibration only after the motor has stopped
    Page 4 saved to flash immediately on entry, right after page 3's onExit()
    started the motor's 2.5 s S-curve braking ramp. saveSettings() disables
    interrupts for the flash erase, freezing that ramp mid-brake and delaying
    the stop by up to a few hundred ms worst case.
    CalResultTab now computes the ratio in onEnter() but defers the write to
    update(), which saves once ctx_.motor.isRunning() is false. onClick() is
    ignored while the save is pending (at most ~2.5 s), so the menu can't
    advance past an unsaved ratio. CalMoveTab::onExit() only calls stop() in
    Motor mode, since stop() on an already-stopped motor starts a pointless
    0->0 r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
    [calibration_menu.cpp]
2026-09-27 docs(firmware): correct flash timing notes and calibration docs
    settings_store.cpp's "not on the stack while interrupts are off" comment
    was misleading (the stack is RAM too); the real reason the buffer is
    static is to keep the 256-byte page off the caller's stack. settings_store.h
    understated the worst-case erase time. Code/CLAUDE.md had a stray
    back-to-back parenthetical and didn't mention KnobAccel's actual file or
    the calibration menu's new save-after-stop behavior.
    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
2026-09-27 fix(firmware): periodically refresh the MAX7219 so a glitch cannot freeze it
    The display module runs on 5 V but is driven with 3.3 V logic, below the
    MAX7219's 3.5 V input-high level. A corrupted SPI frame (more likely with
    fast encoder turns and motor noise) could switch on display-test mode:
    all segments lit, digit writes ignored, until power-off, while the
    firmware kept running. The chip cannot be read back, so the driver now
    remembers its register state and refresh() rewrites it every 250 ms.
    Constraint: MAX7219 registers are write-only
    Rejected: Rewrite config only on full redraws | a stuck display with no redraws would never heal
    Directive: Real fix is a 5 V level shifter on DIN/CLK/C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
    [Code.cpp, max7219.cpp]
2026-09-27 docs: add user calibration instructions
2026-09-27 feat(firmware): report long clicks from ClickDetector
    ClickDetector now returns ClickEvent enum (None/Short/Long) instead of bool,
    so menus can distinguish between short and long presses. Long presses are
    reported on release if held longer than max_short_ms (default 2s).
    - Short presses (≤2s) flip menu pages
    - Long presses (>2s) for pause/resume while pulling wire
    - Both reported once on release; returns None while held or after reporting
    TDD: tests written first, all passing. Firmware builds without warnings.
    [Code.cpp]
2026-09-27 feat(firmware): pass user-knob long clicks to the shown tab
    Implement long-click support through Menu and MenuManager:
    - MenuTab::onLongClick() virtual method (default: stay)
    - Menu::longClick() passes to the open tab's handler
    - MenuInput.user_long_click field never opens a menu
    - Code.cpp distinguishes Short vs Long clicks from ClickDetector
    - All tests pass, firmware builds cleanly
    [Code.cpp]
2026-09-27 feat(firmware): optional x1000 knob step and clampAdd helper
    Adds KnobAccel constructor with max_factor parameter (default 100 for
    backward compatibility with calibration menu), kFastestGapMs constant
    for x1000 scaling, and clampAdd() for safe int32 clamped addition.
    The Working menu's 1 m length steps now work by using KnobAccel(1000).
2026-09-27 feat(firmware): landing maths: slow-down point, creep speed control, stall detection
    Implements pure logic for the Working menu wire-pulling control:
    - slowDownDistanceMm: calculates braking distance for given speed and ramp time
    - shouldSlowDown: determines when to start creep phase before target
    - shouldStop: detects target reached within safety margin
    - estimateCreepPower: estimates motor power from measured wire speed
    - SpeedMeter: measures wire speed over fixed time windows
    - CreepController: adjusts motor power to maintain creep speed
    - StallDetector: detects motor stall from encoder count
    All logic is hardware-free and host-tested via TDD.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
    [run_logic.h]
2026-09-27 feat(firmware): Motor::setSpeed with its own ramp time, isRamping
    Adds Motor::setSpeed(float speed, uint32_t ramp_ms) to drive the motor at an
    exact speed with its own ramp duration, independent of the max-speed setting.
    Also adds Motor::isRamping() to report whether any ramp is in progress. The
    working menu uses this to creep onto target length with precise speed control.
2026-09-27 refactor(firmware): generic NumberEditTab replaces CalLengthTab
    Introduces NumberEditTab, a generic number-editing page for menu use with
    accelerating-step knob control. Replaces the calibration menu's length page,
    keeping its behavior unchanged: same clamping range, same x1/x10/x100 steps,
    same display output. The tab accepts an optional label for future use in the
    Working menu.
    [calibration_menu.cpp]
2026-09-27 feat(firmware): real working menu with pause, stall stop and creep landing
    Replaces the placeholder Working menu (two LabelTab stubs) with the five
    real pages: target length, max speed, thread, pull, done. Page 4 (pull) is
    a small state machine (Running/SlowingDown/Creeping/Paused/Stalled/Stopped)
    that ramps down to a closed-loop creep speed near the target, stops the
    motor at once at target - 1 mm, supports long-click pause/resume, and
    stops on a 10 s stall. run_logic.cpp (already host-tested) is now wired
    into the firmware build.
    Not-tested: on-hardware behavior (Step 5 of the task brief is left to the human; kCreep* constants are still first-guess TUNE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
    [Code.cpp, working_menu.cpp, working_menu.h]
2026-09-27 fix(firmware): control on unrounded mm in shouldStop/shouldSlowDown/SpeedMeter
    ticksToMm() rounds to whole mm. Feeding that into the creep controller made
    a 100 ms SpeedMeter window see the pulled length jump by ±1 mm, so the
    measured speed bounced between neighboring 10 mm/s bands and the tuning
    trace was unreadable; feeding it into shouldStop() made llround(x) >= T-1
    fire up to 0.5 mm before the true target - kStopBeforeMm point. Switching
    these to take the unrounded double mm fixes both.
    Added testShouldStopUnroundedMm (stop now fires exactly at target -
    kStopBeforeMm on fractional input) and testSpeedMeterFractionalMm
    (reset(0.0,0) + update(2.5,100) -> 25.0 mm/s, where the old int64_t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
    [run_logic.h]
2026-09-27 fix(firmware): cut power at once for every target stop; feed exact mm to control
    With this low-side PWM driver, duty 0 = coast, so the 2.5 s ramp used by
    Motor::stop() only keeps driving longer past the target. RunPullTab now
    always calls setSpeed(0.0f, 0) on a target stop instead of ramping down
    when state_ == Running.
    A long click (pause) or a stall also calls stop(), which ramps down over
    2.5 s. Paused/Stalled are not driving states, so shouldStop() was no
    longer checked while the motor still coasted, and it could run far past
    the target. update() now also checks shouldStop() whenever the motor is
    still turning in a non-driving state, and cuts it the same way.
    Both stop paths are factor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
    [working_menu.cpp, working_menu.h]
2026-09-27 docs(firmware): fix stale comments on the ramp/running invariant and the pull page
    motor.h: running_'s comment said "start() was called and stop() was not",
    but setSpeed() with a positive speed also drives the motor without going
    through start(). Updated to cover both.
    CLAUDE.md: documents that a pause/stall coasting into target -
    kStopBeforeMm now also cuts power at once, and that control uses the
    unrounded pulled length (|count| x mm_per_tick) while only the display
    is rounded.
    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
    [motor.h]
2026-09-28 Creation of menu and casing update
    [Assembly.FCStd, Bearing_case.3mf, Bottom_roll.3mf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]
